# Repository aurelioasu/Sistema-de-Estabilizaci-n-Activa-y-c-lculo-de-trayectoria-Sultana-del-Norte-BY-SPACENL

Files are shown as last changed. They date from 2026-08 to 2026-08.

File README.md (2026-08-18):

<p align="center">
  Sultana del Norte — sistema de estabilización y corrección activa de vuelo
</p>

<p align="center">
  
  
  
  
  
  
</p>

<p align="center">
  <strong>Aviónica · control PID · cuatro superficies activas · telemetría · simulación 6-DoF · CFD</strong>
</p>

<p align="center">
  <a href="#descargar-la-aplicación">Descargar app</a> ·
  <a href="#explorar-el-proyecto">Explorar el proyecto</a> ·
  <a href="#arquitectura">Arquitectura</a> ·
  <a href="#galería">Galería</a> ·
  <a href="05-documentacion/informe-tecnico/Reporte-tecnico-Sultana-del-Norte-2026.pdf">Reporte técnico</a>
</p>

# Sultana del Norte

**Sultana del Norte** es un sistema integral de estabilización y corrección activa para un vehículo experimental de pequeño calibre, desarrollado por **Space NL** para ExpoCiencias Nuevo León 2026. El proyecto estudia cómo mitigar la desviación provocada por viento cruzado mediante estimación de actitud, control PID y cuatro canards accionados independientemente.

Este repositorio reúne el proyecto completo: diseño mecánico, evidencia CFD, esquemáticos y PCB, tres programas para ESP32-S3, código fuente de la aplicación Windows, simulación, telemetría, documentación técnica y descargas listas para usar.

> [!IMPORTANT]
> El firmware público calcula y registra las órdenes de control, pero mantiene la actuación física **bloqueada por defecto**. El sistema debe validarse en banco —cableado, sentidos, mezcla y límites— antes de habilitar cualquier movimiento.

## Explorar el proyecto

| Área | Qué contiene | Entrada principal |
|---|---|---|
| 🛰️ **Diseño CAD y aerodinámica** | STL del vehículo, integración del módulo, 21 renders y 72 capturas CFD organizadas por condición y ángulo | [`01-diseno-cad/`](01-diseno-cad/) |
| ⚡ **Electrónica y aviónica** | Esquemático, PCB, BOM interactiva y modelos STEP/OBJ/MTL | [`02-electronica/`](02-electronica/) |
| 🎛️ **Firmware ESP32-S3** | Diagnóstico, control de vuelo y estación terrestre, compilables con Arduino | [`03-firmware-esp32/`](03-firmware-esp32/) |
| 🖥️ **Aplicación Sultana** | Python/PySide6, núcleo C++, módulo Go, configuraciones, modelos, pruebas y compilador Windows | [`04-app-sultana/`](04-app-sultana/) |
| 📚 **Documentación** | Reporte final de 84 páginas, arquitectura, informe CAD y protocolo histórico claramente identificado | [`05-documentacion/`](05-documentacion/) |

## Qué hace el sistema

- Adquiere actitud, aceleración, presión barométrica y posición con BNO085, BMP390 y GPS.
- Ejecuta estimación de actitud y control a **200 Hz** en el ESP32-S3.
- Calcula órdenes limitadas para cuatro superficies activas en configuración cruciforme.
- Registra datos en microSD y transmite telemetría por nRF24L01.
- Recibe y rotula telemetría mediante una estación terrestre ESP32-S3.
- Simula trayectoria y dinámica de seis grados de libertad en la aplicación de escritorio.
- Visualiza mapas, telemetría, canards, fuerzas, Monte Carlo y dispersión de aterrizaje.
- Prepara casos CFD externos con OpenFOAM y ofrece un túnel de viento 2D cualitativo.
- Exporta resultados en CSV/Parquet y conserva escenarios configurables.

## Arquitectura

```mermaid
flowchart LR
    Sensors["BNO085 · BMP390 · GPS"] --> Flight["ESP32-S3<br/>estimación + PID a 200 Hz"]
    Flight --> Safety["interbloqueos<br/>límites ±12°"]
    Safety --> Actuators["4 canards"]
    Flight --> Storage["microSD"]
    Flight <--> AirRadio["nRF24L01<br/>telemetría v2"]
    AirRadio <--> Ground["estación terrestre<br/>ESP32-S3"]
    Ground --> App["app Sultana del Norte"]
    App --> Analysis["telemetría y análisis"]
    App --> SixDoF["simulación 6-DoF<br/>trayectoria"]
    App --> Aero["CFD / túnel 2D"]
```

La descripción de contratos, responsabilidades y límites entre componentes está en [arquitectura-del-sistema.md](05-documentacion/arquitectura/arquitectura-del-sistema.md).

## Descargar la aplicación

La Release [`v1.0.0`](https://github.com/aurelioasu/Sistema-de-Estabilizaci-n-Activa-y-c-lculo-de-trayectoria-Sultana-del-Norte-BY-SPACENL/releases/tag/v1.0.0) contiene dos opciones para Windows 10/11 x64:

| Descarga | Recomendación | Enlace |
|---|---|---|
| Paquete portable ZIP | **Recomendado.** Extrae la carpeta y ejecuta la aplicación; suele iniciar más rápido | [`Sultana-del-Norte-v1.0.0-Windows-x64-portable.zip`](https://github.com/aurelioasu/Sistema-de-Estabilizaci-n-Activa-y-c-lculo-de-trayectoria-Sultana-del-Norte-BY-SPACENL/releases/download/v1.0.0/Sultana-del-Norte-v1.0.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) |
| Ejecutable único | Un solo archivo; el primer inicio puede tardar más mientras prepara sus recursos | [`Sultana-del-Norte-v1.0.0-Windows-x64.exe`](https://github.com/aurelioasu/Sistema-de-Estabilizaci-n-Activa-y-c-lculo-de-trayectoria-Sultana-del-Norte-BY-SPACENL/releases/download/v1.0.0/Sultana-del-Norte-v1.0.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) |

El programa puede abrir y usar simulación, mapas, telemetría y vistas previas sin Docker. **Docker Desktop solo es necesario para ejecutar casos externos de OpenFOAM.**

> [!NOTE]
> Los binarios no tienen firma digital comercial. Windows SmartScreen puede mostrar una advertencia por editor desconocido. Compara el SHA-256 con `SHA256SUMS.txt` de la Release antes de ejecutar:
>
> ```powershell
> Get-FileHash .\Sultana-del-Norte-v1.0.0-Windows-x64.exe -Algorithm SHA256
> ```

## Galería

<table>
  <tr>
    <td width="50%" align="center">
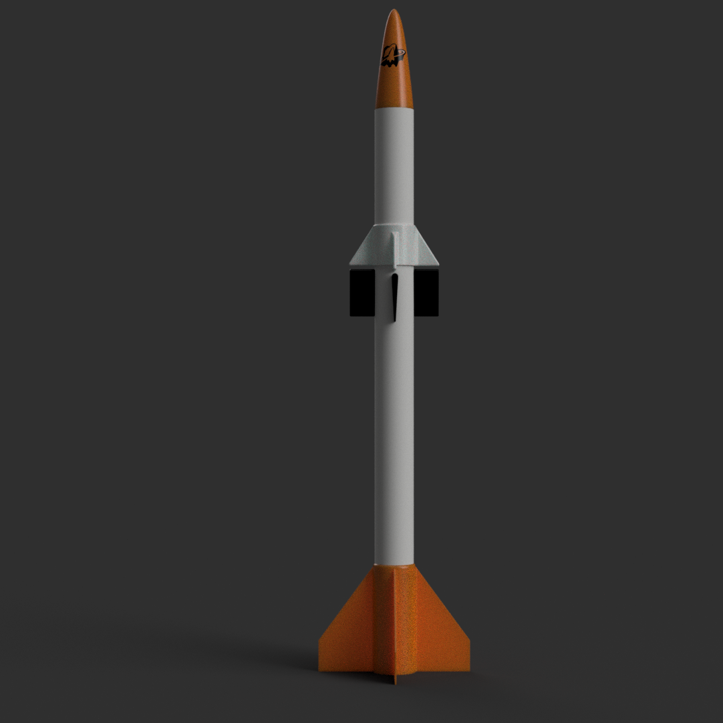
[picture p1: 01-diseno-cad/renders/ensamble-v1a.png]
Ensamble CAD de Sultana del Norte
      <br>
      <strong>Integración mecánica</strong><br>
      Vehículo y módulo de cuatro superficies activas.
    </td>
    <td width="50%" align="center">
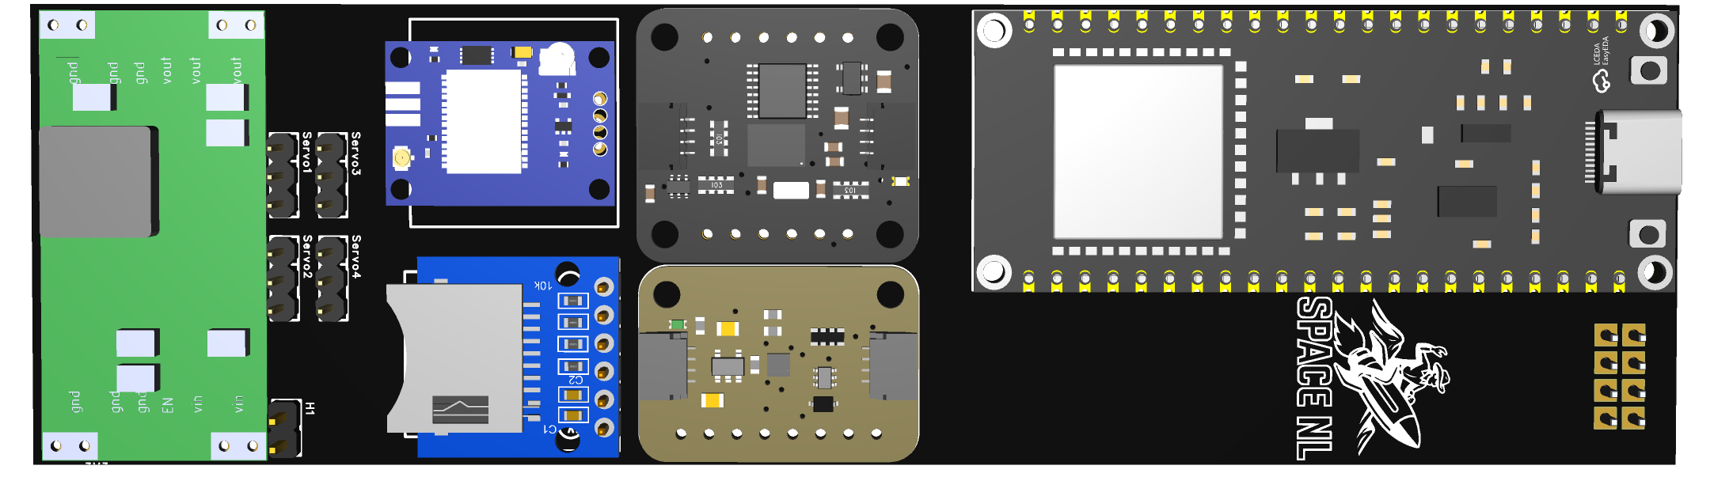
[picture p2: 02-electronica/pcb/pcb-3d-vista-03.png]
PCB y módulos de aviónica
      <br>
      <strong>Aviónica integrada</strong><br>
      ESP32-S3, sensores, radio, almacenamiento y salidas.
    </td>
  </tr>
  <tr>
    <td width="50%" align="center">
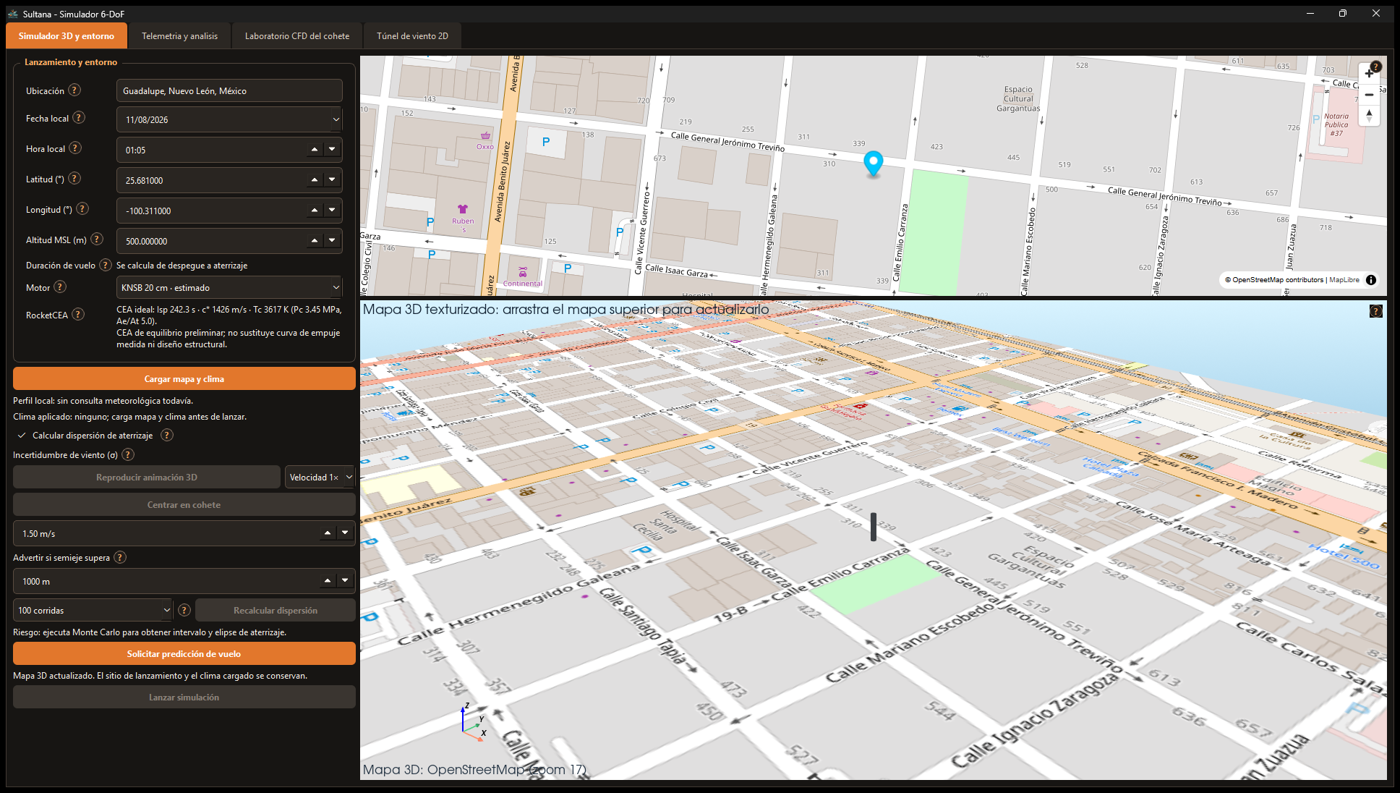
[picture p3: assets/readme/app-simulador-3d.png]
Simulador 3D y mapa de trayectoria
      <br>
      <strong>Simulación y trayectoria</strong><br>
      Escenario, entorno, mapa y reproducción tridimensional.
    </td>
    <td width="50%" align="center">
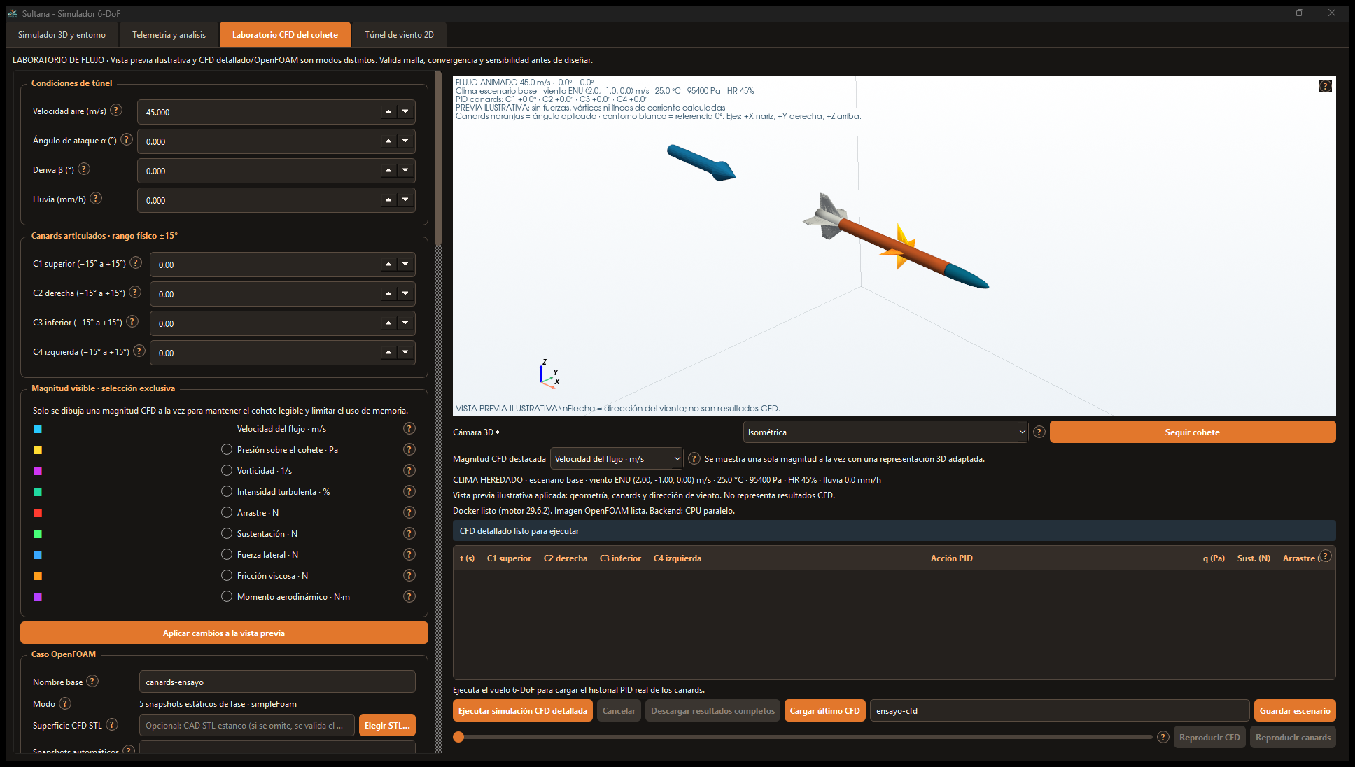
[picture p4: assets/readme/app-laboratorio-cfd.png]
Laboratorio CFD de la aplicación
      <br>
      <strong>Laboratorio aerodinámico</strong><br>
      Vista previa, canards, magnitudes y casos OpenFOAM.
    </td>
  </tr>
</table>

<details>
<summary><strong>Ver telemetría y evidencia de diseño adicionales</strong></summary>

<br>

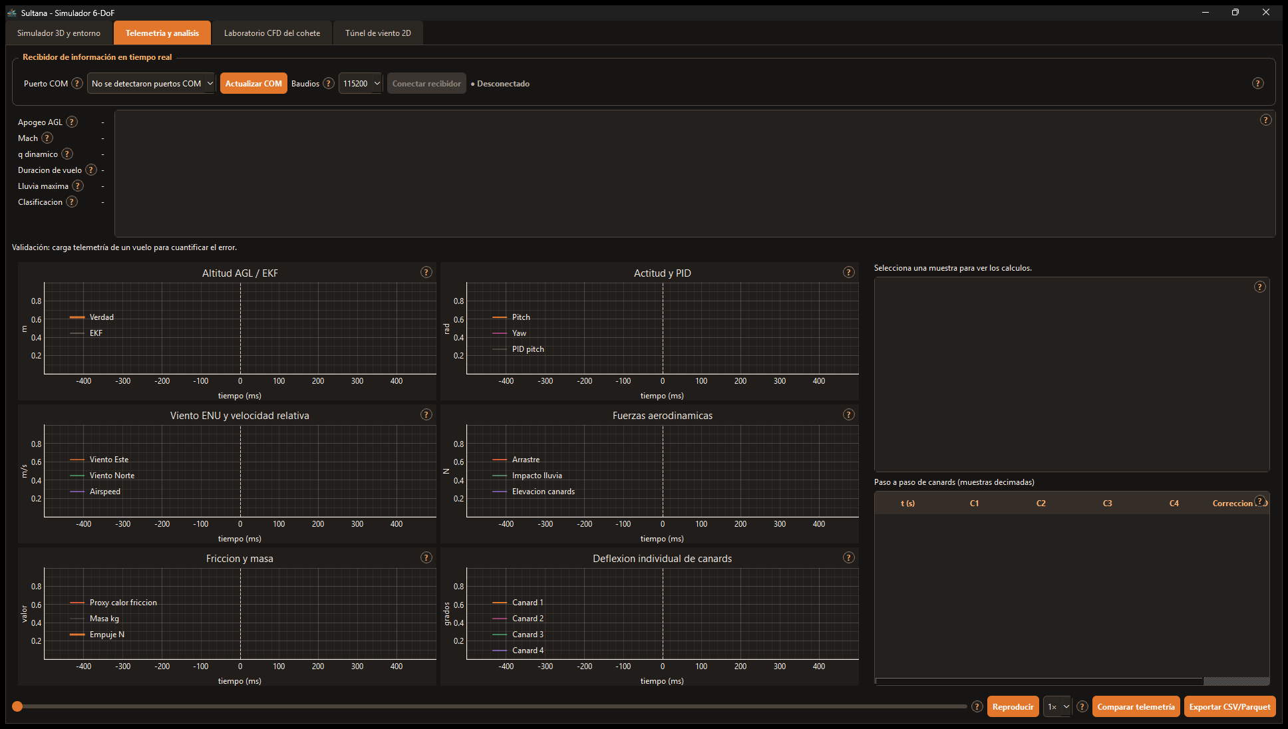
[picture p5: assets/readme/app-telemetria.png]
Panel de telemetría y análisis


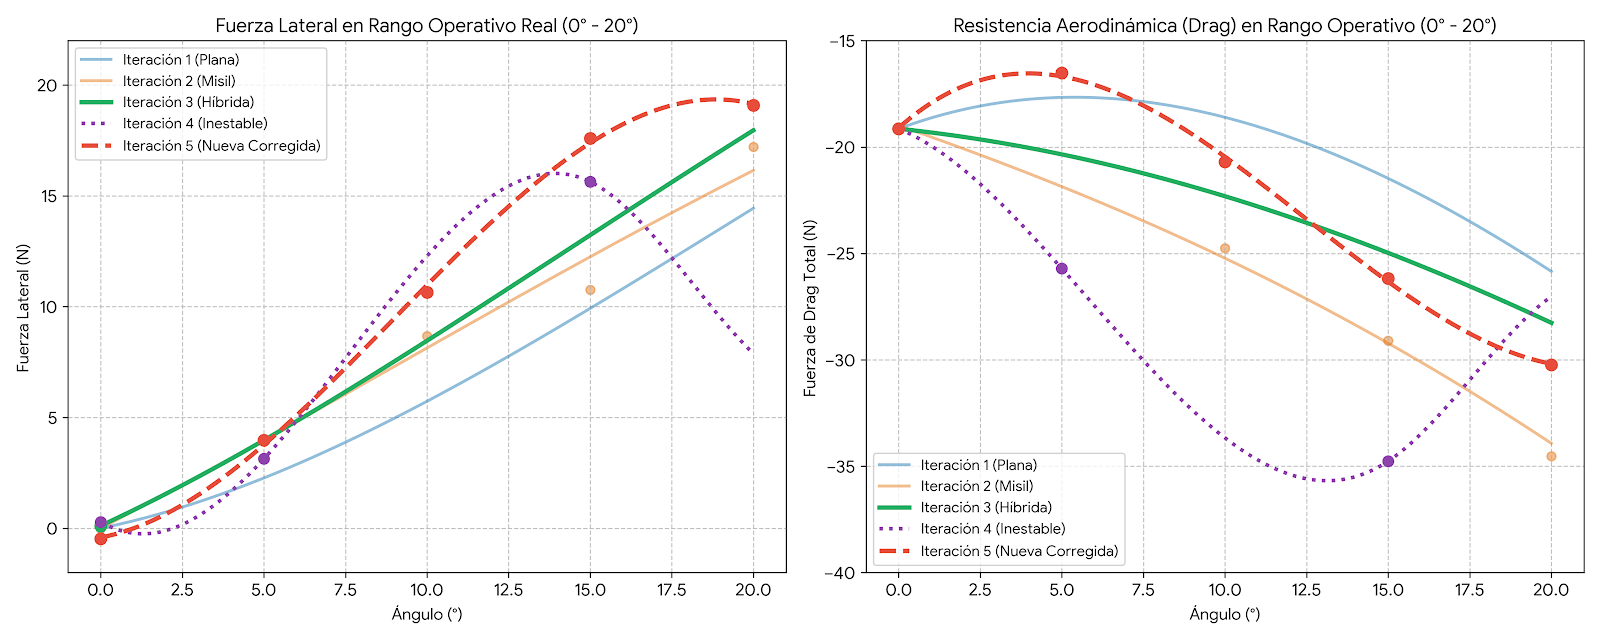
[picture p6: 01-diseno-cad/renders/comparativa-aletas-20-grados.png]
Comparativa aerodinámica de cinco iteraciones


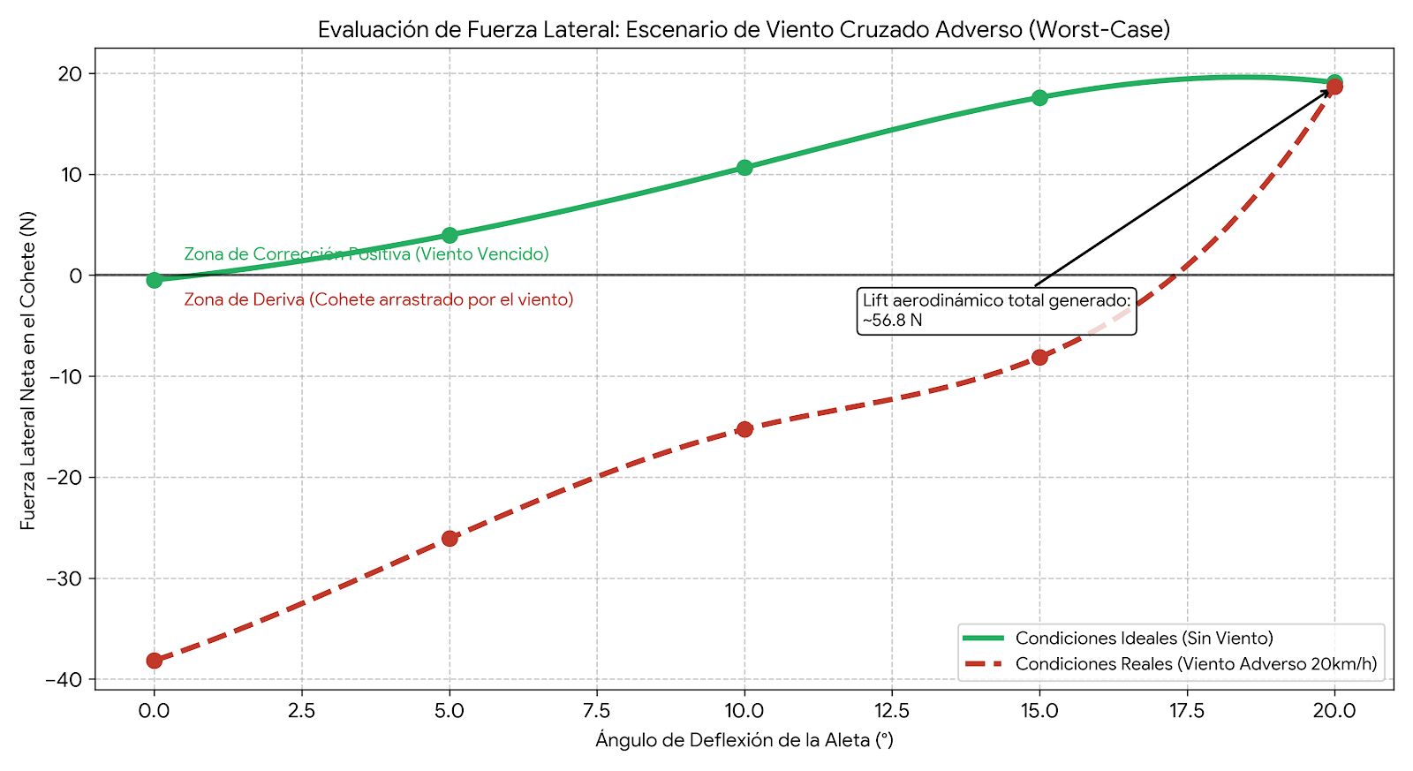
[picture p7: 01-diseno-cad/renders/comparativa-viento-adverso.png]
Evidencia CFD con viento adverso


</details>

## Estado técnico de `v1.0.0`

| Componente | Verificación de referencia |
|---|---|
| Diagnóstico ESP32-S3 | Compila con ESP32 core 3.3.2; 455 483 bytes de flash |
| Control de vuelo ESP32-S3 | Compila con ESP32 core 3.3.2; 429 243 bytes de flash |
| Estación terrestre ESP32-S3 | Compila con ESP32 core 3.3.2; 321 739 bytes de flash |
| Aplicación Python | 112 pruebas superadas |
| Núcleo físico C++ | Compilación Release y 1/1 prueba CTest superada |
| Módulo Kutta/Go | Pruebas superadas en sus paquetes |
| Higiene del repositorio | 16 pruebas de estructura, identidad, secretos y contratos |

Los comandos exactos y las dependencias verificadas están en los README de [firmware](03-firmware-esp32/README.md) y [aplicación](04-app-sultana/README.md).

## Compilar desde el código

### Firmware

Con Arduino CLI, el núcleo ESP32 3.3.2 y las bibliotecas indicadas en [`03-firmware-esp32/README.md`](03-firmware-esp32/README.md):

```powershell
arduino-cli compile --fqbn esp32:esp32:esp32s3 03-firmware-esp32/diagnostico/Diagnostico_Sultana
arduino-cli compile --fqbn esp32:esp32:esp32s3 03-firmware-esp32/control-de-vuelo/Control_Vuelo_Sultana
arduino-cli compile --fqbn esp32:esp32:esp32s3 03-firmware-esp32/estacion-terrena/Estacion_Terrena_Sultana
```

### Aplicación

La aplicación requiere Python 3.11+, Visual Studio Build Tools con C++, CMake y las dependencias declaradas:

```powershell
cd 04-app-sultana
python -m venv .venv
.\.venv\Scripts\python.exe -m pip install -e ".[3d,export,dev]"
.\.venv\Scripts\python.exe run_all.py --no-install
.\.venv\Scripts\python.exe -m app.bootstrap
```

Consulta la [guía completa de la aplicación](04-app-sultana/README.md) para compilar el núcleo, Kutta y el ejecutable Windows.

## Estructura

```text
.
├── 01-diseno-cad/          # STL, renders y evidencia CFD
├── 02-electronica/         # esquemáticos, PCB, BOM y modelos 3D
├── 03-firmware-esp32/      # diagnóstico, vuelo y estación terrestre
├── 04-app-sultana/         # Python, C++, Go, datos y pruebas
├── 05-documentacion/       # informe final, arquitectura y material curado
├── assets/readme/          # portada y capturas optimizadas para GitHub
├── LICENSES/               # licencias de terceros
├── MANIFESTO_DE_CONTENIDO.md
└── THIRD_PARTY_NOTICES.md
```

Los inventarios CSV de CAD, electrónica y documentación registran origen, tamaño y SHA-256. El [manifiesto](MANIFESTO_DE_CONTENIDO.md) explica duplicados, exclusiones y material reservado para Releases.

## Validación, límites y seguridad

> [!CAUTION]
> Este repositorio documenta un sistema experimental. No constituye certificación de aeronavegabilidad ni autorización de lanzamiento.

- La reducción de desviación indicada en el informe corresponde al criterio declarado en escenarios HIL/modelados de hasta 25 km/h; el paquete no contiene series crudas activo/pasivo para reproducir esa cifra.
- Las 72 capturas CFD son evidencia visual de iteración. No sustituyen malla, caso de solver, convergencia ni ensayo físico.
- Al cierre documental del 17 de agosto de 2026, la campaña de vuelo final seguía pendiente.
- El esquema electrónico V1.0 y el pinout vigente del firmware difieren en SDA y tres canales de servo. Revisa la [tabla de discrepancias](02-electronica/README.md#diferencias-pendientes-frente-al-firmware) y confirma continuidad sobre el hardware real.
- Los seguros `PERMITIR_MOVIMIENTO_CANARDS`, `MEZCLA_Y_SENTIDOS_VALIDADOS` y `HABILITAR_SALIDA_PARACAIDAS` se distribuyen en `false`.
- Nunca conectes una carga de despliegue directamente a un GPIO. Inmoviliza el vehículo y trabaja sin propulsión durante pruebas de banco.

## Documentación y material pesado

- [Reporte técnico final — PDF](05-documentacion/informe-tecnico/Reporte-tecnico-Sultana-del-Norte-2026.pdf)
- [Reporte técnico final — DOCX editable](05-documentacion/informe-tecnico/Reporte-tecnico-Sultana-del-Norte-2026.docx)
- [Documentación curada y estados de revisión](05-documentacion/README.md)
- [Notas de la versión v1.0.0](docs/releases/v1.0.0.md)
- [Video principal del proyecto](https://github.com/aurelioasu/Sistema-de-Estabilizaci-n-Activa-y-c-lculo-de-trayectoria-Sultana-del-Norte-BY-SPACENL/releases/download/v1.0.0/Sultana-del-Norte-ExpoC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)
- [Material técnico y multimedia](https://github.com/aurelioasu/Sistema-de-Estabilizaci-n-Activa-y-c-lculo-de-trayectoria-Sultana-del-Norte-BY-SPACENL/releases/download/v1.0.0/Sultana-del-Norte-v1.0.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)
- [Sumas SHA-256](https://github.com/aurelioasu/Sistema-de-Estabilizaci-n-Activa-y-c-lculo-de-trayectoria-Sultana-del-Norte-BY-SPACENL/releases/download/v1.0.0/SHA256SUMS.txt)

Los videos, fotografías completas, visualizadores interactivos y paquetes pesados viven en GitHub Releases para mantener el historial Git ligero.

## Equipo

Proyecto desarrollado por la comunidad **Space NL**:

- Aurelio Salas González
- Gael Sebastián García Azpeytia
- [Sergio Axell Flores Obando](https://github.com/Hir0qwq) · coautor y colaborador
- Asesor: Fernando Alonso Villalobos

<p align="center">
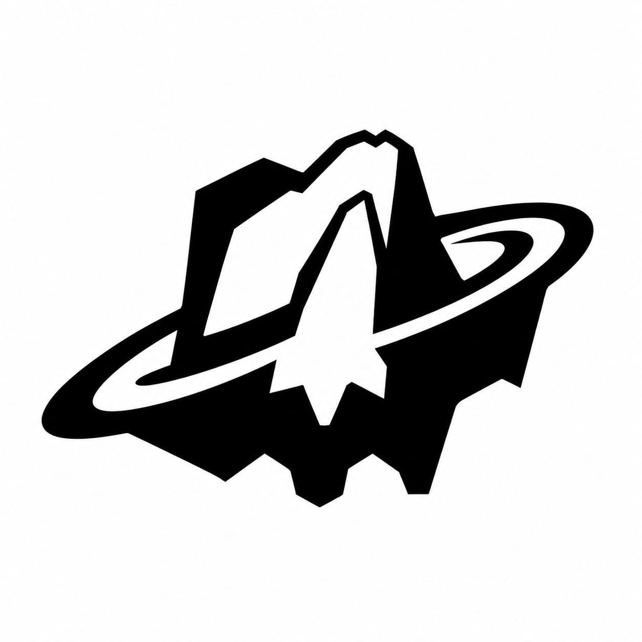
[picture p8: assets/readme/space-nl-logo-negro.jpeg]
Space NL
  <br>
  <sub>Monterrey, Nuevo León · 2026</sub>
</p>

## Licencias y atribuciones

El componente [Kutta](04-app-sultana/kutta/) fue desarrollado por Cesar Gimenes y se conserva bajo licencia MIT. Consulta [`LICENSES/Kutta-MIT.txt`](LICENSES/Kutta-MIT.txt) y [`THIRD_PARTY_NOTICES.md`](THIRD_PARTY_NOTICES.md).

El trabajo propio del repositorio no incluye por ahora una licencia abierta en la raíz; por ello no se concede automáticamente permiso para copiar, modificar o redistribuir ese contenido. Las licencias de terceros conservan todos sus efectos.

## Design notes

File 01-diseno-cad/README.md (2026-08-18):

# Diseño CAD y aerodinámica

Modelos mecánicos, renders y evidencias CFD del vehículo Sultana del Norte y su sistema de superficies de control.

Ensamble de Sultana del Norte

## Contenido

| Ruta | Descripción |
| --- | --- |
| [`modelos/`](modelos/) | Modelo STL listo para inspección o fabricación |
| [`renders/`](renders/) | Ensamble, canards, comparativas y resultados de diseño |
| [`simulacion-cfd/`](simulacion-cfd/) | Capturas organizadas por condición y ángulo |
| [`material-complementario/`](material-complementario/) | Plano de propulsión separado del sistema de control |
| [`INVENTARIO.csv`](INVENTARIO.csv) | Origen, destino, tamaño y SHA-256 de cada archivo |

## Modelo 3D

El archivo principal es [`sultana-del-norte-final-naca.stl`](modelos/sultana-del-norte-final-naca.stl). La entrega contenía un STL “final corregido” y otro de “validación”; ambos tienen exactamente el mismo SHA-256, por lo que se conserva una sola copia con un nombre inequívoco.

Los modelos usados internamente por la aplicación —OBJ, STL y VTP— se encuentran en [`04-app-sultana/data/models/`](../04-app-sultana/data/models/).

## Evidencia CFD

Las 72 capturas se normalizaron en dos familias a 171 m/s:

| Ángulo | Turbulencia | Condiciones reales |
| ---: | ---: | ---: |
| 0° | 7 | 5 |
| 5° | 8 | 6 |
| 10° | 5 | 7 |
| 15° | 9 | 7 |
| 20° | 11 | 7 |

Las imágenes permiten comparar campos y tendencias, pero no contienen por sí solas una malla, un caso de solver ni todos los parámetros necesarios para reproducir el cálculo. Por ello se presentan como evidencia visual de la iteración de diseño, no como validación aerodinámica definitiva.

Comparativa con viento adverso

## Material pesado

Los giros interactivos, MP4 y ZIP de visualización se incluirán en la Release `v1.0.0`. Se omitieron del historial normal las copias exactas que aparecían simultáneamente en las carpetas de documentación y renders.

## Material complementario de propulsión

[`plano-motor-knsb-snl-220-01.pdf`](material-complementario/plano-motor-knsb-snl-220-01.pdf) es un plano independiente del motor. Se conserva como referencia de propulsión y no debe interpretarse como plano del mecanismo de estabilización activa.

## Antes de fabricar

- Confirma unidades, escala y tolerancias en el programa CAD.
- Verifica holguras, ejes y límites mecánicos de los canards.
- Realiza pruebas de banco sin propulsión y con actuadores desenergizados al montar.
- No uses una captura CFD como sustituto de verificación estructural o aerodinámica.

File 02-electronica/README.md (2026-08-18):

# Electrónica

Esquemáticos, PCB, lista de materiales y modelos tridimensionales de la aviónica de Sultana del Norte.

PCB de Sultana del Norte

## Contenido

| Ruta | Descripción |
| --- | --- |
| [`esquematicos/`](esquematicos/) | Esquema completo en SVG y PNG |
| [`pcb/`](pcb/) | Layout, vistas 2D/3D y captura del editor |
| [`bom/interactive-bom.html`](bom/interactive-bom.html) | Lista de materiales interactiva |
| [`modelos-3d/`](modelos-3d/) | PCB en STEP, OBJ y MTL |
| [`recursos/`](recursos/) | Identidad visual usada en el diseño |
| [`INVENTARIO.csv`](INVENTARIO.csv) | Origen, destino, tamaño y SHA-256 |

## Revisión disponible

El esquemático se identifica como `Schematic1`, versión V1.0, actualizado el 10 de agosto de 2026. Incluye ESP32-S3, BNO085, BMP390, GPS MAX10S, microSD, nRF24L01, cuatro conectores de servo y regulación de alimentación.

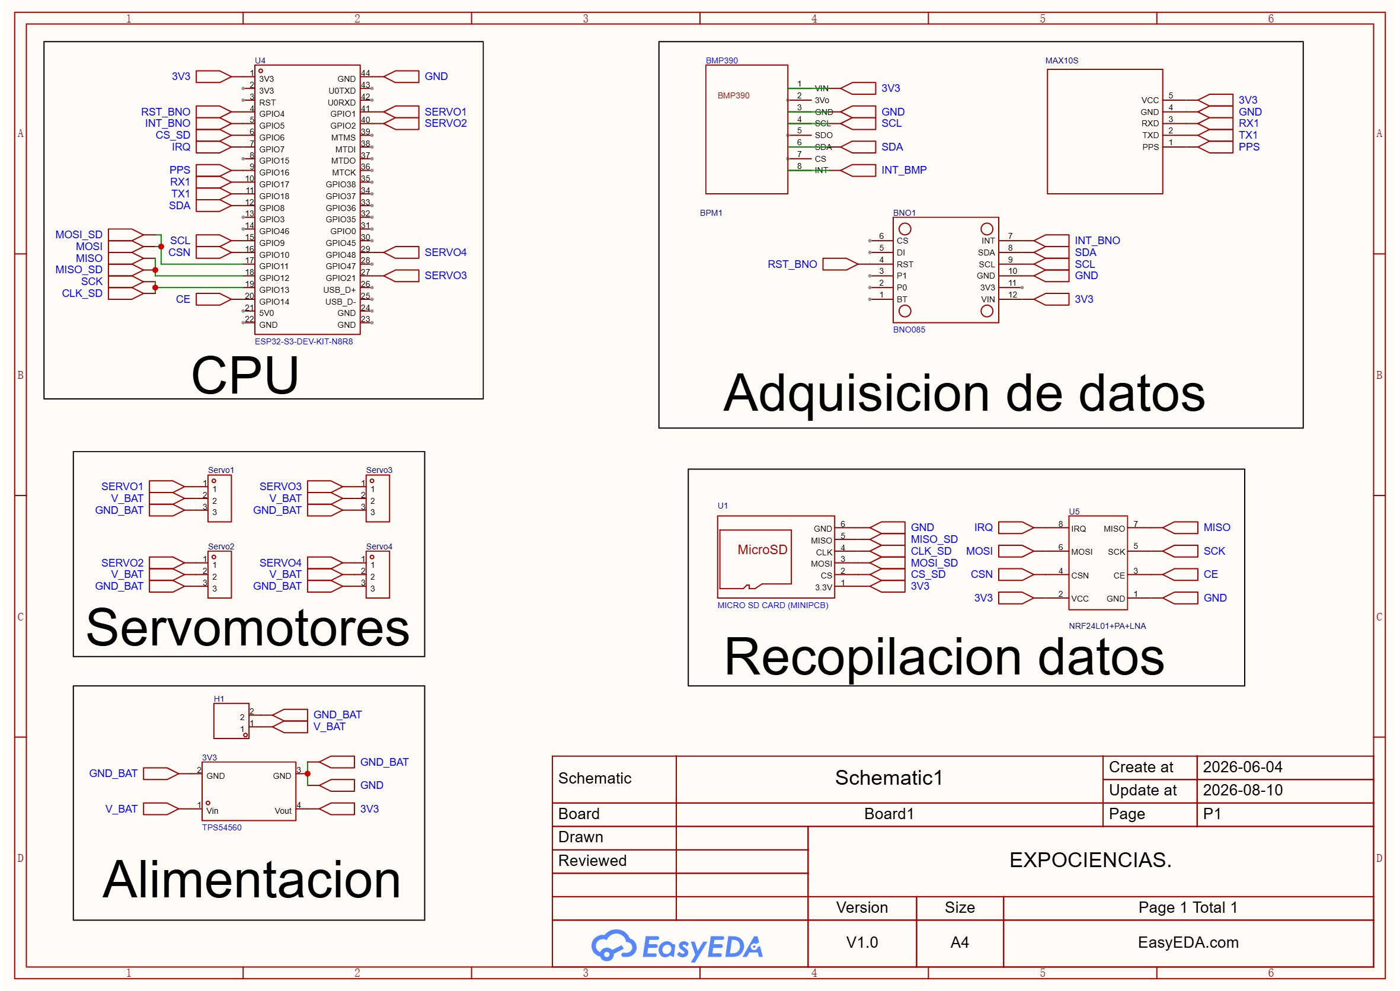
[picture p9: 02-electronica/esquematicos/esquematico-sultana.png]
Esquemático de la aviónica


## Diferencias pendientes frente al firmware

La revisión visual del esquema y el mapa vigente del firmware no coinciden en estas señales:

| Señal | Esquemático V1.0 | Firmware `v1.0.0` |
| --- | ---: | ---: |
| I²C SDA | GPIO 8 | GPIO 18 |
| Servo 1 | GPIO 1 | GPIO 41 |
| Servo 2 | GPIO 2 | GPIO 2 |
| Servo 3 | GPIO 47 | GPIO 21 |
| Servo 4 | GPIO 48 | GPIO 47 |

> [!CAUTION]
> Esta tabla documenta una discrepancia; no decide cuál revisión corresponde a la PCB fabricada. Comprueba continuidad y arnés físico antes de alimentar el sistema. Los bloqueos de movimiento del firmware deben permanecer en `false` hasta completar esa validación.

## Archivos para fabricación e inspección

- [`pcb-sultana.step`](modelos-3d/pcb-sultana.step): modelo mecánico de intercambio.
- [`pcb-sultana.obj`](modelos-3d/pcb-sultana.obj) y [`pcb-sultana.mtl`](modelos-3d/pcb-sultana.mtl): visualización de malla y materiales.
- [`interactive-bom.html`](bom/interactive-bom.html): localización y revisión de componentes.
- [`esquematico-sultana.svg`](esquematicos/esquematico-sultana.svg): versión vectorial del diagrama.

## Seguridad eléctrica

- No alimentes servos desde el regulador lógico de 3.3 V.
- Verifica tierra común, polaridad y corriente disponible antes de conectar cargas.
- No conectes directamente una carga de despliegue al GPIO de alerta.
- Valida la PCB y el firmware como una pareja de revisiones antes de cualquier ensayo dinámico.

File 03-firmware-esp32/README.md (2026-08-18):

# Firmware ESP32-S3

Esta sección contiene los tres programas de aviónica de Sultana del Norte. Los sketches se mantienen separados para que cada función pueda probarse y cargarse desde Arduino IDE sin depender de la aplicación de escritorio.

## Programas

| Programa | Función | Ruta |
| --- | --- | --- |
| Diagnóstico | Pruebas de sensores, almacenamiento, GPS, radio y servos en banco | [`diagnostico/Diagnostico_Sultana/`](diagnostico/Diagnostico_Sultana/) |
| Control de vuelo | Estimación de actitud, control PID, telemetría y máquina de estados | [`control-de-vuelo/Control_Vuelo_Sultana/`](control-de-vuelo/Control_Vuelo_Sultana/) |
| Estación terrena | Recepción nRF24 y salida de telemetría por puerto serie | [`estacion-terrena/Estacion_Terrena_Sultana/`](estacion-terrena/Estacion_Terrena_Sultana/) |

## Plataforma verificada

- Tarjeta: ESP32-S3 Dev Module
- FQBN: `esp32:esp32:esp32s3`
- Núcleo ESP32: 3.3.2
- Monitor serie: 115200 baud
- Radio: nRF24L01, canal 76, 250 kbps, CRC de 16 bits
- Dirección del proyecto: `SNL01`
- Protocolo de telemetría: versión 2, paquetes de 32 bytes

Bibliotecas verificadas:

- Adafruit BNO08x 1.2.5
- Adafruit BMP3XX 2.1.6
- Adafruit BusIO
- Adafruit Unified Sensor
- ESP32Servo 3.1.3
- RF24 1.5.0
- TinyGPSPlus

## Mapa de pines vigente en el firmware

| Señal | GPIO |
| --- | ---: |
| BNO085 reset | 4 |
| BNO085 interrupción | 5 |
| microSD CS | 6 |
| nRF24 IRQ | 7 |
| I²C SCL | 9 |
| nRF24 CSN | 10 |
| SPI MOSI | 11 |
| SPI MISO | 12 |
| SPI SCK | 13 |
| nRF24 CE | 14 |
| GPS PPS | 15 |
| GPS RX | 16 |
| GPS TX | 17 |
| I²C SDA | 18 |
| Servos 1–4 | 41, 2, 21, 47 |
| Alerta de paracaídas | 40 |

> [!CAUTION]
> Algunos archivos visuales de electrónica corresponden a una revisión distinta del cableado. Antes de energizar actuadores, valida este mapa contra la PCB fabricada y el arnés físico.

## Bloqueos de seguridad

El control de vuelo se distribuye con estas salidas deshabilitadas:

```cpp
const bool PERMITIR_MOVIMIENTO_CANARDS = false;
const bool MEZCLA_Y_SENTIDOS_VALIDADOS = false;
const bool HABILITAR_SALIDA_PARACAIDAS = false;
```

No cambies estos valores hasta terminar la calibración mecánica, confirmar los sentidos de cada servo y validar la matriz de mezcla. La salida de alerta nunca debe conectarse directamente a una carga de despliegue.

## Compilación

Desde la raíz del repositorio, con Arduino CLI y el núcleo ESP32 instalados:

```powershell
arduino-cli compile --fqbn esp32:esp32:esp32s3 03-firmware-esp32/diagnostico/Diagnostico_Sultana
arduino-cli compile --fqbn esp32:esp32:esp32s3 03-firmware-esp32/control-de-vuelo/Control_Vuelo_Sultana
arduino-cli compile --fqbn esp32:esp32:esp32s3 03-firmware-esp32/estacion-terrena/Estacion_Terrena_Sultana
```

## Comandos de banco

El sketch de diagnóstico exige la frase `ARMAR SERVOS X08` antes de generar PWM. El control de vuelo acepta `ARMAR SULTANA`, `DESARMAR` y `ESTADO`; aun así, los canards siguen bloqueados mientras los dos seguros de movimiento permanezcan en `false`.

## Resultado de compilación de referencia

| Programa | Flash | RAM global |
| --- | ---: | ---: |
| Diagnóstico | 455 483 bytes | 27 320 bytes |
| Control de vuelo | 429 243 bytes | 27 808 bytes |
| Estación terrena | 321 739 bytes | 20 800 bytes |

Resultados obtenidos el 17 de agosto de 2026 con ESP32 core 3.3.2. El tamaño puede variar ligeramente entre versiones del compilador.

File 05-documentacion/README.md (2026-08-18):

# Documentación de Sultana del Norte

Esta sección reúne la documentación técnica curada del **sistema de estabilización y corrección activa de vuelo Sultana del Norte**. Los archivos se separan por vigencia para evitar que un documento anterior se interprete como la definición actual del hardware o del software.

## Documento vigente

| Documento | Estado | Formatos |
|---|---|---|
| Reporte técnico Sultana del Norte 2026 | **Referencia integral vigente** | [PDF](informe-tecnico/Reporte-tecnico-Sultana-del-Norte-2026.pdf) · [DOCX editable](informe-tecnico/Reporte-tecnico-Sultana-del-Norte-2026.docx) |

El reporte técnico de 84 páginas integra planteamiento, arquitectura, electrónica, modelo físico, control, firmware, CAD, CFD, aplicación, validación declarada, limitaciones y anexos. Cuando exista una discrepancia con un documento de mayo de 2026, prevalecen el código versionado, los README de cada área y este reporte final.

## Material complementario

| Documento | Estado | Uso recomendado | Formatos |
|---|---|---|---|
| Informe de diseño CAD | Complementario | Geometría, integración mecánica, configuración de cuatro superficies y CFD preliminar | [PDF](material-complementario/Informe-diseno-CAD-Sultana-del-Norte.pdf) · [DOCX](material-complementario/Informe-diseno-CAD-Sultana-del-Norte.docx) |
| Protocolo ExpoCiencias NL, mayo de 2026 | **Histórico** | Trazabilidad del desarrollo y de la propuesta inicial | [PDF](material-complementario/Protocolo-ExpoCiencias-NL-mayo-2026.pdf) · [DOCX](material-complementario/Protocolo-ExpoCiencias-NL-mayo-2026.docx) |

> [!CAUTION]
> El protocolo de mayo describe una etapa anterior —incluidos BNO055, dos canards y frecuencias preliminares—. No debe usarse como mapa de conexiones, lista de componentes ni especificación de firmware vigente.

## Manuales operativos vigentes

- [Aplicación Sultana del Norte](../04-app-sultana/README.md): instalación, ejecución, telemetría, simulación, CFD y compilación.
- [Firmware ESP32-S3](../03-firmware-esp32/README.md): sketches, bibliotecas, compilación, pines y bloqueos de seguridad.
- [Electrónica y aviónica](../02-electronica/README.md): esquemáticos, PCB, BOM y discrepancias que requieren validación física.
- [Diseño CAD y CFD](../01-diseno-cad/README.md): modelo 3D, renders, condiciones simuladas e inventario.

## Arquitectura

La vista compacta de componentes y flujo de datos está en [arquitectura-del-sistema.md](arquitectura/arquitectura-del-sistema.md).

## Curaduría

Los manuales antiguos que todavía presentaban el proyecto bajo una identidad ajena no se publicaron: su contenido útil se consolidó en los README vigentes. Los documentos incluidos fueron revisados tanto en texto como visualmente; los PDF son exportaciones verificadas de sus fuentes DOCX. Los tamaños y hashes de estos archivos están en [INVENTARIO.csv](INVENTARIO.csv).

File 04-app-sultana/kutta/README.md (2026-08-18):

# kutta - 2D wind tunnel

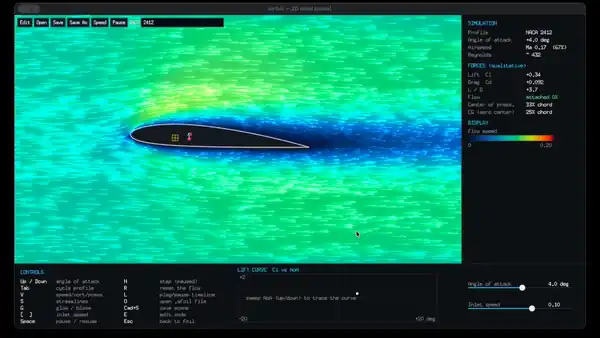
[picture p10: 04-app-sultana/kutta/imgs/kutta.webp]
kutta


A 2D wind tunnel for aeromodelers and anyone who likes watching air misbehave.
It streams a flow past an airfoil and draws the speed field, the vorticity, smoke
streaklines and the lift/drag vectors while you turn the angle of attack. You can
also draw your own shape, cut a wing into wing + flap, animate the control
surfaces, and watch the wake fall apart when you push the angle too far.

It is **qualitative, not validated CFD**. Lattice units stand in for physical
ones, so it gets the *shape* of the flow right (stagnation point, wake, suction
over the top, separation as the angle grows) and the actual numbers wrong. Use it
for intuition and for a demo that looks good on a projector, not for sizing a real
wing.

Written in Go with [Ebitengine](https://ebitengine.org). One executable, nothing
to install alongside it.

## Try it in your browser

**[Open the wind tunnel →](https://crgimenes.github.io/kutta/)**

The whole simulator runs as WebAssembly, with nothing to install. A browser tab
cannot reach your files, so opening and saving `.afoil` scenes, importing SVG and
the native menu are desktop only.

## Download (no Go required)

Grab a prebuilt binary from the
[latest release](https://github.com/crgimenes/kutta/releases/latest). You do
**not** need Go or any developer tools.

| System | File to download |
| --- | --- |
| macOS (Intel or Apple Silicon) | `kutta-darwin-universal.zip` |
| Windows (64-bit, most common) | `kutta-windows-amd64.exe` |
| Windows (ARM) | `kutta-windows-arm64.exe` |
| Linux (Intel/AMD 64-bit) | `kutta-linux-amd64.gz` |
| Linux (ARM 64-bit) | `kutta-linux-arm64.gz` |

### macOS

With [Homebrew](https://brew.sh), one command:

```bash
brew install --cask crgimenes/tap/kutta
```

Or by hand:

1. Download `kutta-darwin-universal.zip` and double-click it to unzip. You get
   `kutta.app`.
2. Move `kutta.app` to your **Applications** folder.
3. Double-click it to run.

The app is signed and notarized by Apple, so it opens normally. The single
universal build runs on both Intel and Apple Silicon, so there is no architecture
to choose.

If macOS says **"kutta.app is damaged and can't be opened"** or complains about
an unidentified developer:

- Make sure the download finished, and unzip before opening (do not run the app
  from inside the `.zip`). Re-download if in doubt.
- Right-click `kutta.app`, choose **Open**, then confirm with **Open** in the
  dialog.
- If it still refuses, open **Terminal** and run (adjust the path if you did not
  move it to Applications):

  ```bash
  xattr -dr com.apple.quarantine /Applications/kutta.app
  ```

### Windows

Download the `.exe` for your machine and double-click it. Windows SmartScreen may
warn you because the app is not from the Microsoft Store: click
**More info → Run anyway**.

### Linux

Download the matching `.gz`, then decompress and run:

```bash
gunzip kutta-linux-amd64.gz
chmod +x kutta-linux-amd64
./kutta-linux-amd64
```

## Run from source

With Go installed:

```bash
go run .
```

On macOS and Windows there is nothing else to install. On **Linux**, Ebitengine
needs Cgo and the system development libraries, so build with `CGO_ENABLED=1`
after installing the packages from the
[Ebitengine install guide](https://ebitengine.org/en/documents/install.html) (on
Debian/Ubuntu: `libgl1-mesa-dev`, `libasound2-dev`, `libxcursor-dev`, `libxi-dev`,
`libxinerama-dev`, `libxrandr-dev`, `libxxf86vm-dev`, `pkg-config`).

## Command-line flags

| Flag | Effect |
| --- | --- |
| `-scene path.afoil` | load a scene at startup instead of the interactive foil |
| `-fullscreen` | start in full screen |
| `-hidecontrols` | hide every panel and control, showing only the flow image |

The flags combine into a kiosk. `kutta -scene wing.afoil -fullscreen -hidecontrols`
boots straight into a scene, full screen, with nothing on screen but the flow.
The keys still work, so a controller wired to the keyboard (or a person) can drive
angle of attack and speed with no visible UI. A bad `-scene` path logs a warning
and falls back to the normal foil rather than failing to start.

## Controls

| Key | Action |
| --- | --- |
| ↑ / ↓ | angle of attack |
| Tab | cycle NACA profile |
| V | speed / vorticity / pressure field |
| S | streamlines |
| G | glow / bloom |
| `[` `]` | inlet speed |
| Space | pause / resume |
| N | single step (while paused) |
| R | reset the flow |
| E | open the editor |
| O | open an `.afoil` scene |
| Cmd+O | open (native file dialog) |
| Cmd+S | save |
| Cmd+Shift+S | save as |
| L | play / pause the animation |
| Esc | back to the foil |

Type a code in the field at the top (`2412`, `0012`, `23012`, ...) to pick any
NACA 4- or 5-digit foil, not just the ones on Tab. And if you type `neko` in that
field, you get a cat. It has terrible aerodynamics. That is the point.

## The editor

Press **E**. Draw a shape with the pen, drag its vertices, and curve an edge by
pulling out a Bézier handle. Cut a closed outline at a vertex and rejoin two loose
ends to split one airfoil into separate parts, which is how you turn a wing into
wing + flap that each follow the real profile.

**Tab** switches between geometry and animate. In animate you scrub a timeline and
drop a keyframe for each part's pose, so a flap can deploy and retract on a loop
while the flow keeps running. Scenes save as `.afoil`, a small
[Filo](https://github.com/crgimenes/filo) s-expression file; see `examples/` for a
few (`flap.afoil`, `neko.afoil`).

Geometry does not have to be drawn by hand or be an airfoil at all. **File →
Import SVG…** — or simply **dragging an `.svg` or `.afoil` file onto the
window** — loads a vector drawing as a scene: one object per subpath, with
curves flattened and the group scaled onto the grid. A car silhouette, a
building section or a bridge deck from Inkscape or Illustrator drops straight
into the tunnel. (On Windows and Linux the native file dialogs are not wired
up yet, so drag and drop is the way to open files there.) Scene files can
also reference drawings directly with
`(svg "path" chord leadX leadY [subpath])`, alongside the existing
`(naca "2412" ...)` and `(dat "file.dat" ...)` sources. Transforms are not
interpreted (flatten them before exporting) and holes become solid.

## How it works

- **Solver** (`lbm`): a 2D Lattice-Boltzmann method (D2Q9, BGK). An open channel
  with a free stream from the left; the body is a no-slip wall via half-way
  bounce-back. Forces come from a pressure integral over the body faces, so it
  captures form drag and lift. Skin friction is ignored, which means drag is
  understated. That is a known limit, not a bug to file.
- **Geometry** (`foil`): NACA 4- and 5-digit airfoils straight from their
  closed-form equations. A whole catalog with nothing stored on disk.
- **Scenes** (`scene`, `sceneio`): multi-object shapes with per-vertex Bézier
  handles, cuts, and keyframe animation, read and written as `.afoil`.
- **Visualization** (`viz`): color maps for the scalar fields and a smoke-tracer
  particle system pushed around by the velocity field.
- **App** (`main.go`, `game.go`, `editor.go`): the Ebitengine loop, the editor,
  and the native macOS/Windows menu (via [glaze](https://github.com/crgimenes/glaze)).

`lbm`, `foil`, `scene` and `viz` carry no rendering dependency and are unit tested
headlessly. `cmd/snapshot` renders the fields to PNG without a GPU, which is how
the physics gets sanity-checked: lift rising with angle of attack, the drag
bucket, the force signs coming out right.

## Gallery

Scenes built in the editor and run in the tunnel. Each one is an `.afoil` file
under [`examples/`](examples/), so you can open it yourself with
`kutta -scene examples/<name>.afoil`.

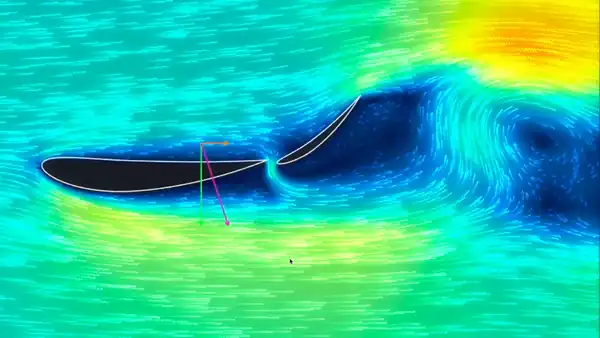
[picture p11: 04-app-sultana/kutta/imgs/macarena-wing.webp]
Ferrari's Macarena rear wing simulated in kutta


**Ferrari's "Macarena" rear wing.** The upper element rotates flat on the
straight and the wake behind it collapses, dropping downforce by more than half,
then swings back for the corner. Both profiles are inverted NACA sections, so
lift is negative: this wing pushes down.
Scene: [`examples/macarena.afoil`](examples/macarena.afoil).

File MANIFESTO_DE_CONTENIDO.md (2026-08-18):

# Manifiesto de contenido

Este documento registra cómo se transforma la entrega original en la publicación curada de Sultana del Norte.

## Reglas de selección

- Se conserva una sola copia de cada archivo idéntico.
- Se priorizan modelos editables, archivos de fabricación y evidencias técnicas legibles.
- Los videos, fotografías completas y paquetes pesados se entregan mediante GitHub Releases.
- Se excluye material ajeno al sistema de estabilización y corrección activa de vuelo.
- La documentación vigente se distingue de borradores y revisiones históricas.
- No se publican entornos virtuales, cachés, resultados temporales ni binarios antiguos.

## Estado por área

| Área | Fuente | Destino | Estado |
| --- | --- | --- | --- |
| Diseño mecánico y CFD | Entrega técnica | `01-diseno-cad/` | Curado: 97 archivos en Git y 12 activos únicos reservados para Release |
| Electrónica | Entrega técnica | `02-electronica/` | Curado: 15 de 15 archivos incluidos |
| Firmware ESP32 | Área de trabajo local | `03-firmware-esp32/` | Completo: 3 sketches limpios y compilados |
| Aplicación | Área de trabajo local | `04-app-sultana/` | Completo: fuentes Python, C++, Go, configuraciones y datos |
| Documentación | Entrega técnica | `05-documentacion/` | Curada: 3 documentos en DOCX/PDF, arquitectura y manuales enlazados al código |
| Multimedia pesado | Entrega técnica | GitHub Release | Listo: 162 fotos/videos, 12 recursos CAD dinámicos y 1 BOM interactiva |

## Decisiones verificadas

### Diseño CAD y CFD

- La entrega contiene 126 archivos y 109 contenidos únicos por SHA-256.
- Se incluyeron en Git 97 contenidos únicos: modelo STL, plano complementario, renders y 72 resultados CFD.
- Doce contenidos dinámicos únicos —HTML, MP4 y ZIP— se reservaron para la Release.
- Se descartaron 17 copias exactas; entre ellas, los dos STL con nombres de revisión distintos resultaron idénticos.
- El detalle archivo por archivo se encuentra en [`01-diseno-cad/INVENTARIO.csv`](01-diseno-cad/INVENTARIO.csv).

### Electrónica

- Los 15 archivos entregados son distintos por SHA-256 y se conservaron.
- STEP, OBJ, MTL y BOM mantienen su formato original; las rutas públicas se normalizaron.
- El detalle se encuentra en [`02-electronica/INVENTARIO.csv`](02-electronica/INVENTARIO.csv).

### Software

- Se excluyeron entornos virtuales, cachés, resultados, compilaciones y ejecutables anteriores.
- La aplicación conserva 46 archivos Python, 5 C++, 107 de Kutta, 7 configuraciones y 31 recursos de datos.
- La identidad anterior fue eliminada de rutas, interfaz, protocolo propio y textos públicos.

### Documentación

- El reporte técnico final de 84 páginas se conserva como referencia integral vigente en DOCX y PDF verificado.
- El informe CAD se conserva como material complementario en ambos formatos.
- El protocolo de mayo de 2026 se conserva como revisión histórica y se advierte que no define el hardware ni el firmware vigentes.
- Cinco manuales anteriores con identidad heredada no se publican; sus instrucciones útiles se consolidaron en los README de firmware, electrónica y aplicación.
- El detalle y los hashes se encuentran en [`05-documentacion/INVENTARIO.csv`](05-documentacion/INVENTARIO.csv).

### Licencias

- Se conserva el texto MIT original del componente Kutta en [`LICENSES/Kutta-MIT.txt`](LICENSES/Kutta-MIT.txt).
- Las atribuciones y el estado de licencia del código propio se explican en [`THIRD_PARTY_NOTICES.md`](THIRD_PARTY_NOTICES.md).

## Paquetes cerrados para `v1.0.0`

| Activo | Tamaño aproximado | Estado |
|---|---:|---|
| Aplicación Windows portable | 413.15 MiB | ZIP verificado íntegramente |
| Aplicación Windows en un archivo | 410.27 MiB | Ejecutable abierto y revisado visualmente |
| Video principal ExpoCiencias 2026 | 686.29 MiB | Copia íntegra de la entrega seleccionada |
| Material técnico y multimedia | 876.62 MiB | ZIP verificado íntegramente; 175 archivos de material y 2 documentos guía |

Los cuatro activos están por debajo del límite de 2 GiB por archivo de GitHub Releases. Sus hashes finales se publican en `SHA256SUMS.txt` junto con la Release `v1.0.0`.

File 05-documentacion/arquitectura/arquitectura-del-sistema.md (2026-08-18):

# Arquitectura del sistema

Sultana del Norte distribuye la adquisición, el control, la telemetría y el análisis entre la aviónica embarcada y una estación terrestre.

```mermaid
flowchart LR
    subgraph Vehiculo["Vehículo experimental"]
        Sensores["BNO085 · BMP390 · GPS"] --> ESP32["ESP32-S3<br/>estimación y control"]
        ESP32 --> Seguridad["Interbloqueos y límites"]
        Seguridad --> Canards["4 actuadores / canards"]
        ESP32 --> Registro["Registro microSD"]
        ESP32 <--> RadioV["Radio nRF24L01"]
    end

    RadioV <--> RadioT["Estación terrestre ESP32-S3"]
    RadioT --> App["Aplicación Sultana del Norte"]
    App --> Telemetria["Telemetría y análisis"]
    App --> Simulacion["Simulación 6-DoF y trayectoria"]
    App --> CFD["Laboratorio CFD y túnel 2D"]
```

## Responsabilidades

| Componente | Responsabilidad principal | Fuente vigente |
|---|---|---|
| Firmware de vuelo | Leer sensores, estimar actitud, calcular órdenes, registrar y transmitir | [`03-firmware-esp32/control-de-vuelo/`](../../03-firmware-esp32/control-de-vuelo/) |
| Firmware de diagnóstico | Validar módulos y recorridos de actuadores en banco | [`03-firmware-esp32/diagnostico/`](../../03-firmware-esp32/diagnostico/) |
| Estación terrestre | Recibir radio y exponer telemetría rotulada | [`03-firmware-esp32/estacion-terrena/`](../../03-firmware-esp32/estacion-terrena/) |
| Aplicación Windows | Configurar escenarios, simular, visualizar y analizar | [`04-app-sultana/`](../../04-app-sultana/) |
| Electrónica | Interconexión física, alimentación, adquisición y actuación | [`02-electronica/`](../../02-electronica/) |
| Mecánica | Integración del módulo y geometría aerodinámica | [`01-diseno-cad/`](../../01-diseno-cad/) |

## Contratos importantes

- La dirección de radio propia del sistema es `SNL01` en ambos extremos.
- Los paquetes binarios de vuelo y las líneas de estación terrestre deben mantenerse compatibles.
- Los actuadores permanecen bloqueados por defecto hasta validar cableado, mezcla, sentidos y límites en banco.
- El pinout definido en firmware es la referencia de software. El esquema electrónico conserva discrepancias documentadas que requieren confirmación física antes de energizar actuadores.
- Los resultados CFD y HIL conservados son modelados o preliminares salvo que el documento indique explícitamente una medición experimental.

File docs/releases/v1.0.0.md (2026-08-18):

# Sultana del Norte v1.0.0

Primera publicación integral y curada del sistema de estabilización y corrección activa de vuelo de **Space NL**.

## Incluye

- diseño mecánico, modelo STL, renders y 72 resultados CFD organizados;
- esquemáticos, PCB, BOM interactiva y modelos electrónicos 3D;
- firmware de diagnóstico, vuelo y estación terrestre para ESP32-S3;
- código fuente completo de la aplicación Sultana del Norte en Python, C++ y Go;
- ejecutable único y paquete portable para Windows 10/11 x64;
- reporte técnico final, informe CAD y documentación de arquitectura;
- video principal, 162 fotografías/videos de evidencia y 12 recursos CAD dinámicos únicos.

## Descargas

| Archivo | Uso |
|---|---|
| `Sultana-del-Norte-v1.0.0-Windows-x64-portable.zip` | Opción recomendada: extraer y ejecutar `Sultana-del-Norte.exe` |
| `Sultana-del-Norte-v1.0.0-Windows-x64.exe` | Aplicación completa en un solo archivo |
| `Sultana-del-Norte-ExpoCiencias-2026.mp4` | Video principal del proyecto |
| `Sultana-del-Norte-v1.0.0-material-tecnico-y-multimedia.zip` | Evidencia fotográfica, videos, CAD dinámico y BOM interactiva |
| `SHA256SUMS.txt` | Sumas de verificación de todos los archivos anteriores |

## Verificación de esta versión

- aplicación Python: **112 pruebas superadas**;
- núcleo físico C++: **1/1 prueba CTest superada**;
- módulo aerodinámico Go: **todos los paquetes superados**;
- higiene e identidad del repositorio: **16 pruebas superadas**;
- los tres programas ESP32-S3 compilan correctamente y mantienen desactivadas las salidas de movimiento y despliegue por defecto;
- ambos formatos Windows fueron abiertos y revisados visualmente.

## Antes de usar

Los ejecutables no cuentan con firma digital comercial, por lo que Windows SmartScreen puede mostrar una advertencia de editor desconocido. Compara la suma SHA-256 de tu descarga con `SHA256SUMS.txt`.

La aplicación funciona sin Docker para simulación, mapas, telemetría y análisis. Docker Desktop solo es necesario para ejecutar casos externos de OpenFOAM.

> [!CAUTION]
> Es software experimental. Revisa el pinout contra el hardware real, conserva los seguros de actuación desactivados durante pruebas de banco y nunca conectes una carga de despliegue directamente a un GPIO.

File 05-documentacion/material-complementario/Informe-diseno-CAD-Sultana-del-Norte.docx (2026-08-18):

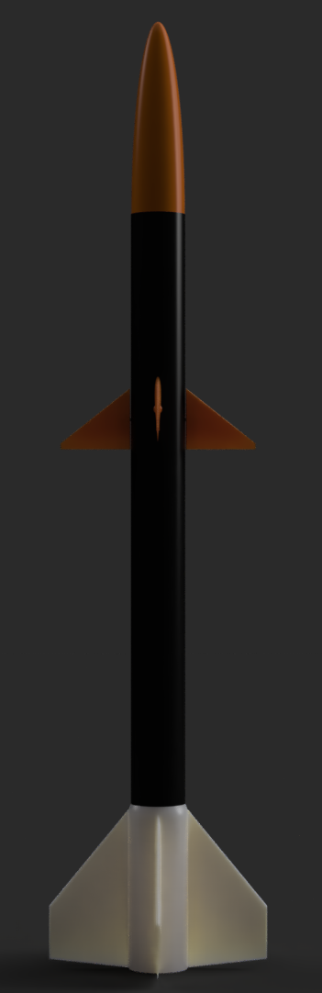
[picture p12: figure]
P1#y1

# Optimización Aerodinámica e Integración Mecánica del Sistema de Control Canard para el Cohete "Sultana del Norte"

# 1. Introducción y Planteamiento del Problema

El desarrollo de vehículos aeroespaciales experimentales requiere sistemas de estabilización y control direccional altamente precisos. Este proyecto se centra en el diseño, análisis aerodinámico e integración mecánica de un módulo de actuación canard para el cohete "Sultana del Norte" El objetivo principal radicó en lograr un control activo en dos ejes dentro de las severas restricciones volumétricas de un fuselaje de dos pulgadas de diámetro. Para asegurar que la solución propuesta poseyera un rigor técnico a la altura de una competencia nacional, la metodología empleada abarcó desde simulaciones balísticas para definir las condiciones de contorno, hasta dinámica de fluidos computacional (CFD) iterativa para perfeccionar la geometría de las superficies de control.

# 2. Perfil de Vuelo y Arquitectura Mecánica

El primer paso para el diseño del sistema consistió en comprender las exigencias cinemáticas a las que estaría sometido el vehículo. Utilizando el software OpenRocket, se simuló el perfil de vuelo integrando la masa, la longitud del fuselaje, la geometría de las ojivas y las aletas estabilizadoras pasivas. En esta fase final, se terminó de colocar los componentes definitivos que irán dentro del cohete, como los paracaídas del sistema de recuperación y el hardware del sistema electrónico, además de ajustar las opciones de empuje del motor. Esta simulación consolidada proyectó que el apogeo máximo se mantenga en 670 m y estableció una velocidad máxima de 142 m/s durante su fase propulsiva. Esta magnitud se estableció como el límite operativo fundamental para evaluar la resistencia estructural y predecir el comportamiento de la capa límite sobre los canards.

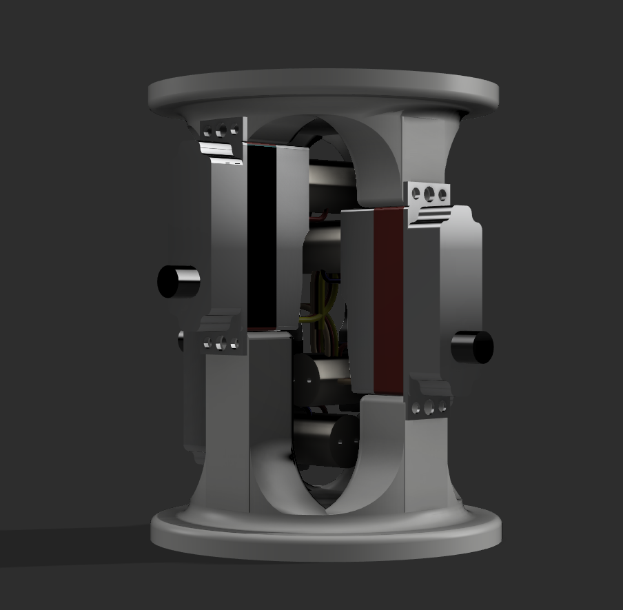
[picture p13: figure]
P7#y1

Resolver el empaquetamiento de los actuadores representó uno de los mayores desafíos de ingeniería del proyecto. El requerimiento de control de doble eje exigía la incorporación de cuatro servomotores independientes dentro de un espacio cilíndrico sumamente restringido. La solución adoptada consistió en un soporte interno altamente compacto que posiciona los ejes de rotación de forma simétrica transversalmente, pero introduce un desfase vertical intencional de 8 milímetros entre los pares de motores opuestos. Lejos de ser un defecto asimétrico, esta decisión de diseño actúa como un seguro mecánico crítico; garantiza que ni las superficies exteriores ni los mecanismos interiores colisionen al accionarse de manera simultánea. Adicionalmente, se modificó el punto de anclaje de las aletas movibles al servomotor para dotar al ensamble de una mayor resistencia estructural ante las cargas aerodinámicas. Además, esta densidad de empaquetamiento dota al módulo de una notable versatilidad, permitiendo su futura integración en fuselajes aún más esbeltos de hasta 1.5 pulgadas.

# 3. Justificación de la Configuración Cruciforme (4 Aletas)

Una de las decisiones arquitectónicas más importantes fue la adopción de un sistema cruciforme (cuatro aletas) en lugar de una configuración triforme (tres aletas) o monowing (dos aletas). Si bien un arreglo de tres aletas ofrece ventajas en términos de peso reducido y menor arrastre frontal, introduce una complejidad computacional masiva para el piloto automático (autopilot). En una configuración triforme, el control de los ejes de cabeceo (pitch), guiñada (yaw) y alabeo (roll) está fuertemente acoplado, requiriendo que múltiples aletas actúen de forma asimétrica y coordinada para lograr un movimiento en un solo eje.

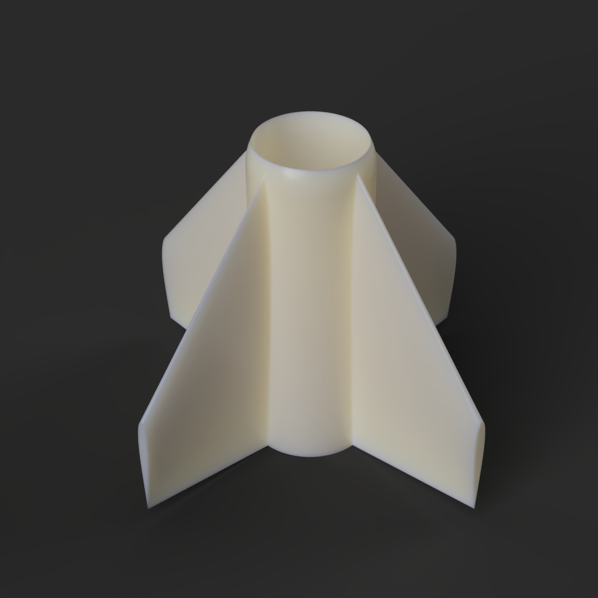
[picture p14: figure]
P10#y1

Por el contrario, la configuración cruciforme en orientación "+" o "x" permite desacoplar los ejes de control de manera ortogonal. Esto significa que un par de aletas opuestas controla exclusivamente el cabeceo, mientras que el otro par perpendicular controla independientemente la guiñada. Esta ortogonalidad simplifica drásticamente el algoritmo de estabilización del cohete, incrementa la efectividad del control direccional a velocidades supersónicas y transónicas, y garantiza una redundancia mecánica donde el vehículo mantiene autoridad de vuelo predecible incluso bajo turbulencias asimétricas.

# 4. Metodología de Actuación y Control Dinámico

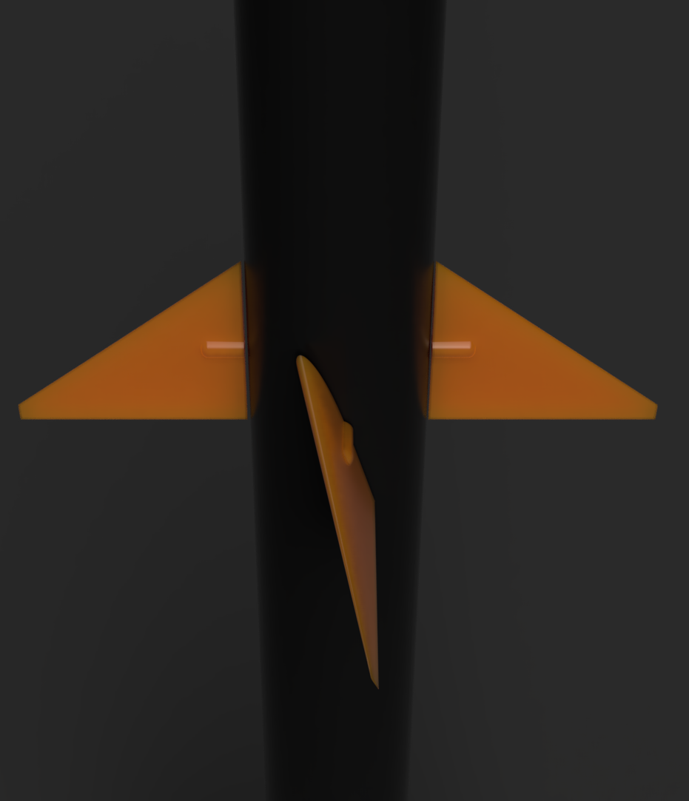
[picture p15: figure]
P13#y1

Desde la perspectiva del accionamiento aerodinámico, el diseño evolucionó hacia una configuración de rotación pivotante (canards all-moving), inspirada profundamente en la filosofía de control y estabilización de los misiles tácticos. A diferencia de las iteraciones iniciales basadas en cinemática de flaps, esta arquitectura definitiva emplea un perfil alar sumamente delgado diseñado para cortar el flujo transónico minimizando la resistencia parásita frontal (drag). La integración mecánica se resolvió mediante un robusto anclaje circular posicionado en la región central de la aleta. La fundamentación técnica detrás de esta decisión radica en acercar el eje de rotación al centro de presión hidrodinámico, lo cual equilibra las cargas aerodinámicas y reduce drásticamente el esfuerzo de torque exigido a los servomotores. Operativamente, para mantener la estabilidad del flujo y evitar una separación turbulenta (stall) que actúe como freno direccional severo, el sistema fue restringido mecánica y lógicamente a un rango de movimiento máximo de 20°. Las simulaciones CFD respaldan que esta configuración centralizada maximiza la autoridad direccional en su rango operativo útil, simplifica enormemente la manufactura y mitiga los puntos de falla bajo los regímenes de alta vibración inducidos por el motor

# 5. Evolución Aerodinámica Iterativa

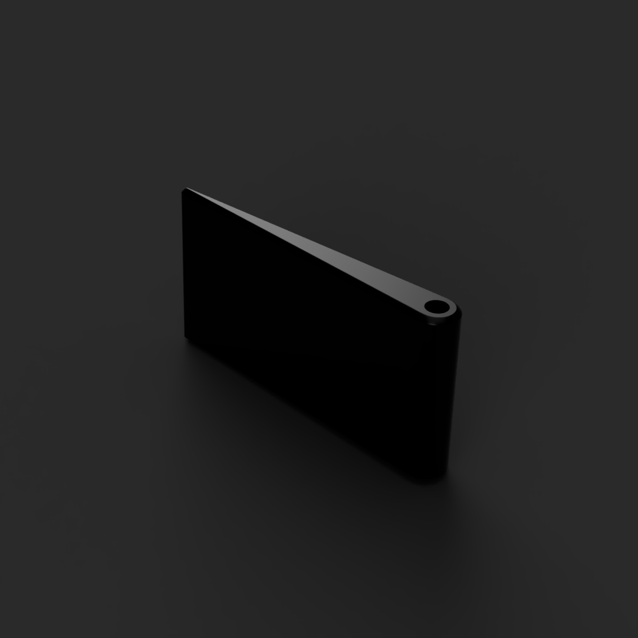
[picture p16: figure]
P15#y1

Comprendiendo que el diseño aeroespacial rara vez alcanza el óptimo en su primera etapa, se estructuró un análisis iterativo basado en los resultados obtenidos de simulación. La primera iteración evaluó un perfil de aleta predominantemente plano. Empíricamente, este diseño actuó como una barrera agresiva contra el flujo, generando una notable fuerza lateral, pero induciendo simultáneamente una separación turbulenta que se tradujo en un drag prohibitivo.

Buscando mitigar este arrastre parásito, se analizaron perfiles simétricos empleados en misiles tácticos y aviación de alta velocidad, como las series NACA y el RAE 100, utilizando herramientas de evaluación polar (Airfoil Tools). La segunda iteración adoptó uno de estos perfiles hidrodinámicos. No obstante, las pruebas CFD revelaron que la búsqueda excesiva de un bajo coeficiente de resistencia comprometió la efectividad del control, generando un área de presión insuficiente y reduciendo la fuerza direccional a niveles subóptimos.

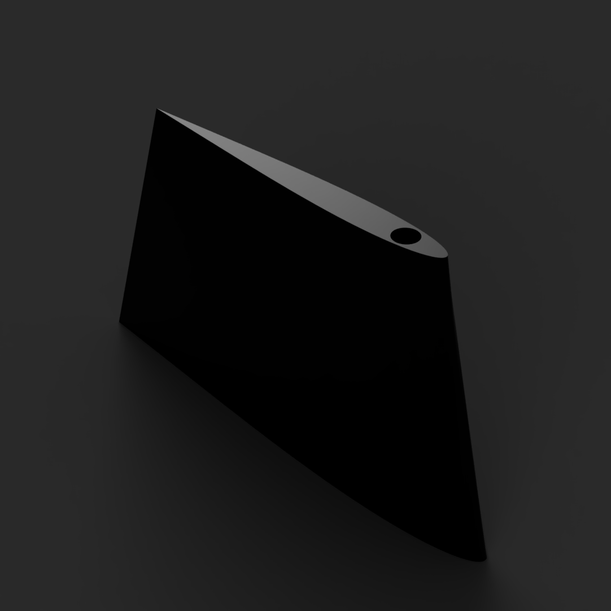
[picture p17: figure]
P17#y1

La tercera iteración nació como una respuesta de síntesis a estos hallazgos. Se desarrolló una geometría híbrida que combinó el área proyectada extendida del primer modelo con el contorno aerodinámico del segundo. Esta hibridación permitió que el flujo de aire se mantuviera adherido a la superficie por más tiempo, retrasando el fenómeno de entrada en pérdida (stall) y capitalizando sobre la sustentación.

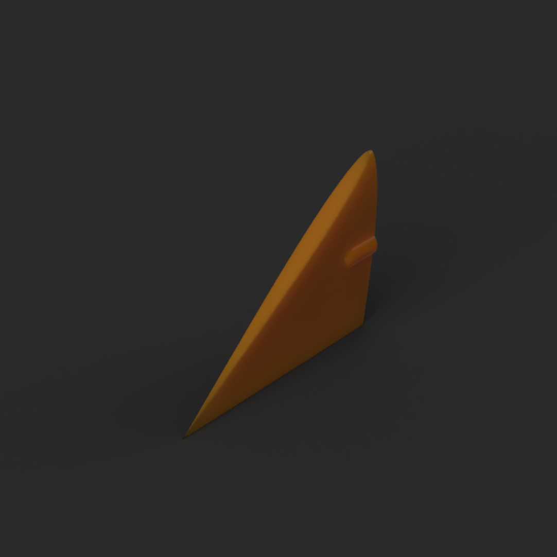
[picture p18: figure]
P18#y1

Buscando simplificar aún más la manufactura, se desarrolló una cuarta iteración realizando unas aletas similares a los misiles balísticos, manteniendo una filosofía diferente a la utilizada anteriormente. Se diseñó con un ángulo de 45° de ataque, manteniendo una línea recta al final de la cuerda del perfil, y se utilizó exactamente el mismo perfil aerodinámico de las aletas estabilizadoras inferiores del cohete (NACA 1940). Además, fue acompañada mecánicamente con un límite de deflexión máximo de 20°. Sin embargo, debido a que el modelado CAD se realizó simplemente mediante una extrusión del perfil alar y un corte directo a 45°, el diseño causaba una severa inestabilidad aerodinámica a partir de los ángulos de ataque comprendidos entre los 15° y 22°.

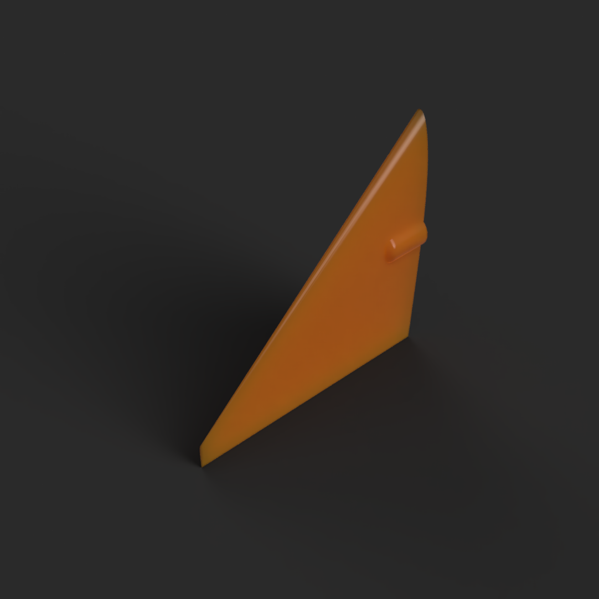
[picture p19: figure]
P19#y1

Para solucionar este problema, se optó por realizar una quinta iteración (Aleta 4 Corregida) mediante una solevación (lofting) de dos perfiles idénticos. Esta técnica permitió mantener las dimensiones generales y el agresivo ángulo de ataque de 45°, pero logrando un redondeo orgánico esencial para mantener la estabilidad del flujo de aire sobre la superficie aerodinámica. Esta corrección dio resultados sumamente positivos: mejoró el Downforce (fuerza lateral), redujo sustancialmente el Drag (resistencia) y arrojó una gráfica de ángulo-fuerza perfectamente estable y predecible.

P20#y1

# 6. Análisis CFD en Escenario Crítico: Viento Cruzado Adverso

Para validar el diseño final antes de su implementación física, las simulaciones no se limitaron a escenarios ideales. Se ejecutaron pruebas CFD con las condiciones ambientales reales proyectadas para el día de la prueba, el 8 de agosto: temperatura ambiente de 30 °C (303.15 K), humedad relativa del 50%, y ráfagas de viento cruzado de 20 km/h (5.55 m/s).

Para llevar la evaluación al límite de sus capacidades operativas (Worst-Case Scenario), la simulación se configuró explícitamente para que este viento lateral chocara en la dirección contraria a la que se quería desviar el cohete. A pesar de que el viento incidente generaba un empuje opuesto masivo, las pruebas demostraron la excepcional eficiencia de la aleta solevada en sus primeros 15° a 20° de actuación. La superficie de control fue capaz de generar aproximadamente 30 N de sustentación lateral neta, logrando vencer completamente la carga atmosférica adversa y garantizando la autoridad del vehículo sobre su trayectoria.

P24#yIS1

# 7. Modelado Matemático y Análisis Comparativo

Para dotar al proyecto de un respaldo analítico escalable, los datos discretos de las simulaciones CFD de cada aleta fueron procesados matemáticamente. Se emplearon regresiones polinomiales y de splines cúbicos para modelar con precisión la curva de fuerza a lo largo de los grados de rotación, capturando el pico de sustentación direccional y el colapso por stall. Se desarrolló un sistema de predicción universal en Excel que aplica el principio de proporcionalidad dinámica, permitiendo predecir la fuerza exacta para cualquier ángulo y velocidad.

# 8. Selección de Materiales y Análisis de Esfuerzos Estructurales

La viabilidad de las superficies de control no solo depende de su eficiencia aerodinámica, sino también de su integridad mecánica bajo cargas dinámicas críticas. Para la manufactura de los canards, se seleccionó Ácido Poliláctico (PLA) utilizando tecnología de manufactura aditiva por deposición de material fundido (FDM). Contar con la capacidad de gestionar la impresión 3D de manera interna no solo acelera la iteración rápida de prototipos durante la fase de diseño, sino que asegura una transición directa hacia la manufactura de medianas producciones o módulos de repuesto con total autonomía operativa. El PLA ofrece un excelente equilibrio entre alta rigidez estructural, bajo peso y precisión dimensional, características vitales para mantener la fidelidad del perfil aerodinámico híbrido durante el vuelo.

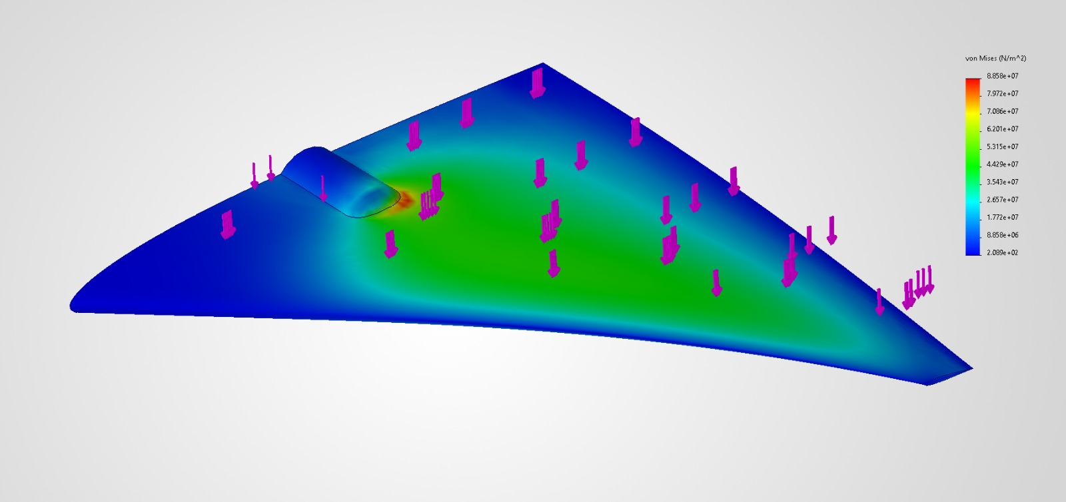
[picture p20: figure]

Para validar empíricamente que el material polimérico soportaría las fuerzas direccionales extremas calculadas en la simulación, se sometió el modelo CAD definitivo a un Análisis de Elementos Finitos (FEA). Se aplicó una matriz de carga distribuida a lo largo del perfil de la aleta, emulando la presión dinámica del flujo de aire transónico incidente, y se definió el eje de rotación del servomotor como la restricción geométrica (punto de anclaje).

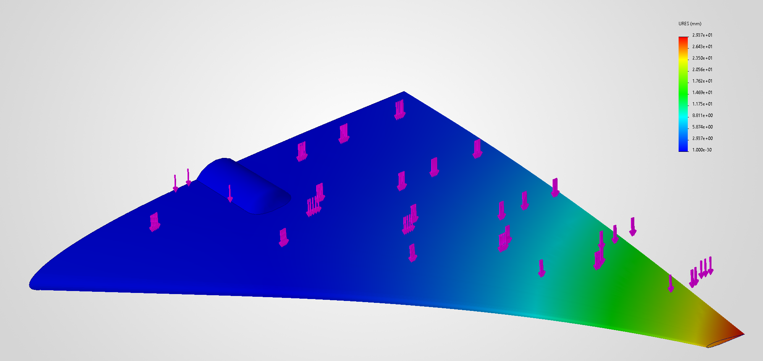
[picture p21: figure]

Los resultados de la simulación de Tensión de Von Mises y Deformación Equivalente evidencian el comportamiento estructural del ensamble. Como se observa en los gradientes térmicos, la concentración de esfuerzos se localiza predominantemente en la raíz del eje de anclaje, indicando que el punto pivote absorbe exitosamente el torque máximo sin transferir estrés crítico al resto de la aleta. El cuerpo principal del canard se mantiene en zonas de bajo estrés, garantizando que no se superará el límite elástico del material. Finalmente, la flexibilidad inherente del PLA extruido actúa como un amortiguador estructural frente a ráfagas de aire, confirmando que la pieza mantiene amplios márgenes de seguridad.

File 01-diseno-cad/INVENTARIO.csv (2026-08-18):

origen_relativo | destino_relativo | bytes | sha256 | estado | nota
DISEÑO 3D\Extra\SNL-220-01 (2).pdf | 01-diseno-cad\material-complementario\plano-motor-knsb-snl-220-01.pdf | 348995 | E4BA56619235488BD9E29C3F7439E1493221A27651E1FEE3752F99012845285B | incluido_en_git | Plano de propulsión complementario; no forma parte del control activo
DISEÑO 3D\Extra\Ensamble (versión FINAL CORREGIDA EN BASE AL NACA).stl | 01-diseno-cad\modelos\sultana-del-norte-final-naca.stl | 2491084 | D81434E7AD33A059F55FB67FD0851A4AFFF841BB18453B16E8A0A0EB2F696FF2 | incluido_en_git | Modelo final; idéntico por hash al STL de validación
DISEÑO 3D\Img_Doc\Aletas_movibles_2_2026-Aug-03_10-26-20AM-000_CustomizedView24306284595.png | 01-diseno-cad\renders\aletas-moviles.png | 76096 | 97D59BF0DD689B9CC885301B0BBD1FBBDDFFC6C3312ED7648C5E3EA85DD7F798 | incluido_en_git | Render o evidencia de diseño seleccionada
DISEÑO 3D\Img_Doc\Aletas_v3_2026-Aug-03_10-25-53AM-000_CustomizedView24889502668.png | 01-diseno-cad\renders\aletas-v3.png | 63396 | E172F44A896C04C66995FCD47117EA4E38081B3CF960FB19B189F924D0802077 | incluido_en_git | Render o evidencia de diseño seleccionada
DISEÑO 3D\Img_Doc\qaewrfwqfteqwg.png | 01-diseno-cad\renders\captura-analisis-cad.png | 223525 | F581665285ACEF162450F916B4D69A6DC99A9F760796B414415172CF971562A7 | incluido_en_git | Render o evidencia de diseño seleccionada
DISEÑO 3D\Img_Doc\Captura de pantalla 2026-08-09 023957.png | 01-diseno-cad\renders\captura-cad-01.png | 47739 | B6B4F396160FB1813D5875FD6D2BA8BE55931B1338A9872FE527ADBFE718FF5C | incluido_en_git | Render o evidencia de diseño seleccionada
DISEÑO 3D\Img_Doc\Captura de pantalla 2026-08-10 014944.png | 01-diseno-cad\renders\captura-cad-02.png | 445387 | 85300854A150A9B53E4EA0846562AC664D1A7BC9D7DA0446A32CBC39C5D673C7 | incluido_en_git | Render o evidencia de diseño seleccionada
DISEÑO 3D\Img_Doc\Captura de pantalla 2026-08-10 015124.png | 01-diseno-cad\renders\captura-cad-03.png | 403508 | D37170B9B883BF33DB1B1B2E2A8374C4C70D07508FD3681AC3EACBF5CC2B63D6 | incluido_en_git | Render o evidencia de diseño seleccionada
DISEÑO 3D\Img_Doc\Comparativa_5_Aletas_20grados.png | 01-diseno-cad\renders\comparativa-aletas-20-grados.png | 233643 | A30D4DFBC9E203C14E0F806C4F95DF2054BA3376338E918B99ADE08840438449 | incluido_en_git | Render o evidencia de diseño seleccionada
DISEÑO 3D\Img_Doc\Comparativa_Viento_Adverso.png | 01-diseno-cad\renders\comparativa-viento-adverso.png | 190400 | B93F108151AA22390ED9E87802C6BFD7ADF4C342EE33F141EDD1822F1C8E403F | incluido_en_git | Render o evidencia de diseño seleccionada
DISEÑO 3D\Img_Doc\a14a20b0-a5d2-491b-9090-8d9ba845c551.PNG | 01-diseno-cad\renders\detalle-canards-01.png | 227646 | CFC12AB3A433D1FF97DF07AF674D5ED213D161E805872F6C6D5E5143856F9681 | incluido_en_git | Render o evidencia de diseño seleccionada
DISEÑO 3D\Img_Doc\d9d912a1-a6be-426d-b33b-d932e41537a7.PNG | 01-diseno-cad\renders\detalle-canards-02.png | 80610 | FEB238F3BA800A753ECCC9F611E2FEEBBA346CCC2BF6B234AEFEE2B261E93678 | incluido_en_git | Render o evidencia de diseño seleccionada
DISEÑO 3D\Img_Doc\Ensamble_todo_2026-Aug-03_10-01-46AM-000_CustomizedView24358796562.png | 01-diseno-cad\renders\ensamble-completo.png | 174208 | A2FD24016B1BC83828233C19E9C85B792E83CEE09917DC94AB695C9A8227E0CC | incluido_en_git | Render o evidencia de diseño seleccionada
DISEÑO 3D\Img_Doc\Ensamble todo v1.png | 01-diseno-cad\renders\ensamble-v1.png | 235234 | 3DB466B152F6AC6FD70E7F27BE8D60852D94F8E564C91A3E04A8E2AA3CD8A174 | incluido_en_git | Render o evidencia de diseño seleccionada
DISEÑO 3D\Img_Doc\Ensamble todo v1A.png | 01-diseno-cad\renders\ensamble-v1a.png | 267720 | 47BD1519025AE51624A75AD5369C9188AA1F002E2D487F225606856F497783F0 | incluido_en_git | Render o evidencia de diseño seleccionada
DISEÑO 3D\Img_Doc\Ensamble_(versin_de_validacin)_2026-Aug-09_09-51-00AM-000_CustomizedView27181243055.png | 01-diseno-cad\renders\ensamble-validacion-vista-01.png | 74784 | 59C00CED8B01A1C6B3DB97065BF9344D220765CFF782EF6BAB8BC7B3A893B5CC | incluido_en_git | Render o evidencia de diseño seleccionada
DISEÑO 3D\Img_Doc\Ensamble_(versin_de_validacin)_2026-Aug-09_09-51-33AM-000_CustomizedView48707317181.png | 01-diseno-cad\renders\ensamble-validacion-vista-02.png | 75386 | 0AF71E074D0B46CA84FCAF73FF1871884F58B3420EBEAFF49FD121D1EA3582BD | incluido_en_git | Render o evidencia de diseño seleccionada
DISEÑO 3D\Img_Doc\Ensamble_(versin_de_validacin)_2026-Aug-09_09-52-05AM-000_CustomizedView14069356933.png | 01-diseno-cad\renders\ensamble-validacion-vista-03.png | 97237 | 480B85548B46480E9FAA8296A86077856B0263D5B38C588564F2BEC9E8BA0AB1 | incluido_en_git | Render o evidencia de diseño seleccionada
DISEÑO 3D\Img_Doc\Ensamble_(versin_de_validacin)_2026-Aug-09_09-52-54AM-000_CustomizedView25760274848.png | 01-diseno-cad\renders\ensamble-validacion-vista-04.png | 140534 | 9068017820AD800C9796F2308561E906ECBC6F43A2CAF0D8A0E159FE5D89030E | incluido_en_git | Render o evidencia de diseño seleccionada
DISEÑO 3D\Img_Doc\Ensamble_(versin_de_validacin)_2026-Aug-09_11-58-14PM-000_CustomizedView11922554831.png | 01-diseno-cad\renders\ensamble-validacion-vista-05.png | 118314 | 0B0BC7B8E4E4284A868C2DF8BC175D9873A2F00E024F680F29BECD626F35ADE4 | incluido_en_git | Render o evidencia de diseño seleccionada
DISEÑO 3D\Img_Doc\Ensamble_(versin_de_validacin)_2026-Aug-10_12-00-43AM-000_CustomizedView10826954976.png | 01-diseno-cad\renders\ensamble-validacion-vista-06.png | 139007 | 472198EF7335B51AA405D61D533587DE7FF782EF6A37AC3B6D7DD0FCAABE679F | incluido_en_git | Render o evidencia de diseño seleccionada
DISEÑO 3D\Img_Doc\Openrocket Grafica.png | 01-diseno-cad\renders\simulacion-openrocket.png | 122354 | 0E8BC0A1E6AA8E8AB591130FF93983E0FD556A84DEA54982288F227A8D918156 | incluido_en_git | Render o evidencia de diseño seleccionada
DISEÑO 3D\Img_Doc\Sin_ttulo_2026-Aug-03_10-29-32AM-000_CustomizedView25921842192.png | 01-diseno-cad\renders\vista-ensamble-canards.png | 69176 | 2EAEE3330980113F30529C9315B209E982976B751665D421CFB1FE5E38ADB3C2 | incluido_en_git | Render o evidencia de diseño seleccionada
DISEÑO 3D\Img_CFD\All 171 Irl Cond\0° 171 Irl Cond\0 171 TB_1.png | 01-diseno-cad\simulacion-cfd\condiciones-reales-171-ms\angulo-00\resultado-01.png | 155114 | 0AC0C88DE86F23ADAE17AF0F41A1E0687ACCB6DB13EBD69888862A9F062B34B6 | incluido_en_git | Resultado CFD conservado con condición y ángulo normalizados
DISEÑO 3D\Img_CFD\All 171 Irl Cond\0° 171 Irl Cond\0 171 TB_2.png | 01-diseno-cad\simulacion-cfd\condiciones-reales-171-ms\angulo-00\resultado-02.png | 315837 | B47FE5BA83633125FD987F1767A24AA762512812BD803E22EEEA7CC0D41511AC | incluido_en_git | Resultado CFD conservado con condición y ángulo normalizados
DISEÑO 3D\Img_CFD\All 171 Irl Cond\0° 171 Irl Cond\0 171 TB_3.png | 01-diseno-cad\simulacion-cfd\condiciones-reales-171-ms\angulo-00\resultado-03.png | 378158 | CC8B253EE05ECAE5C0141CD61D8821A03F71F721B89AEA0655415AA0F80BAD29 | incluido_en_git | Resultado CFD conservado con condición y ángulo normalizados
DISEÑO 3D\Img_CFD\All 171 Irl Cond\0° 171 Irl Cond\0 171 TB_4.png | 01-diseno-cad\simulacion-cfd\condiciones-reales-171-ms\angulo-00\resultado-04.png | 341036 | 22A66608A2C8ED3288D19A67142D879FAEE8F40C7CE6B1C9B75CD228821DCB9F | incluido_en_git | Resultado CFD conservado con condición y ángulo normalizados
DISEÑO 3D\Img_CFD\All 171 Irl Cond\0° 171 Irl Cond\0 171 TB.png | 01-diseno-cad\simulacion-cfd\condiciones-reales-171-ms\angulo-00\resultado-05.png | 60751 | AC7CB2452AEE1E8563D91B0C0A463E4771A5F16CB257D80E6C2F2567EC18B682 | incluido_en_git | Resultado CFD conservado con condición y ángulo normalizados
DISEÑO 3D\Img_CFD\All 171 Irl Cond\5° 171 Irl Cod\5 171(1)_1.png | 01-diseno-cad\simulacion-cfd\condiciones-reales-171-ms\angulo-05\resultado-01.png | 150734 | F7E800378BBF1664AEA952FACAB83633ABB3C31F5F27C3C16874571EEAA37DA3 | incluido_en_git | Resultado CFD conservado con condición y ángulo normalizados
DISEÑO 3D\Img_CFD\All 171 Irl Cond\5° 171 Irl Cod\5 171(1)_2.png | 01-diseno-cad\simulacion-cfd\condiciones-reales-171-ms\angulo-05\resultado-02.png | 317936 | F0E5630092895B03D40777B135359C454D4DCE37E3E4F08290E00D030EBA30E7 | incluido_en_git | Resultado CFD conservado con condición y ángulo normalizados
DISEÑO 3D\Img_CFD\All 171 Irl Cond\5° 171 Irl Cod\5 171(1)_3.png | 01-diseno-cad\simulacion-cfd\condiciones-reales-171-ms\angulo-05\resultado-03.png | 358590 | 44242D1F10F4E5CB9216B408E7D54740A24CAC3B037B804D4D5B37FA49A08404 | incluido_en_git | Resultado CFD conservado con condición y ángulo normalizados
DISEÑO 3D\Img_CFD\All 171 Irl Cond\5° 171 Irl Cod\5 171(1)_4.png | 01-diseno-cad\simulacion-cfd\condiciones-reales-171-ms\angulo-05\resultado-04.png | 255311 | 978E04FABD7D7CBEE37C88FB96C0CF0484FCEEE16FCA5084690B9CAC70C26943 | incluido_en_git | Resultado CFD conservado con condición y ángulo normalizados
DISEÑO 3D\Img_CFD\All 171 Irl Cond\5° 171 Irl Cod\5 171(1)_5.png | 01-diseno-cad\simulacion-cfd\condiciones-reales-171-ms\angulo-05\resultado-05.png | 367514 | 53D2C1E8B5088FE8BC854517D0154C653AF6C046AA21133144754E8BB89317F0 | incluido_en_git | Resultado CFD conservado con condición y ángulo normalizados
DISEÑO 3D\Img_CFD\All 171 Irl Cond\5° 171 Irl Cod\5 171(1).png | 01-diseno-cad\simulacion-cfd\condiciones-reales-171-ms\angulo-05\resultado-06.png | 50365 | 74B22703A439F7F9D70668B08DFD9321365BEBA03ED80B7D5EE302067E1537A7 | incluido_en_git | Resultado CFD conservado con condición y ángulo normalizados
DISEÑO 3D\Img_CFD\All 171 Irl Cond\10° 171 Irl Cond\10 171(1)_1.png | 01-diseno-cad\simulacion-cfd\condiciones-reales-171-ms\angulo-10\resultado-01.png | 49702 | 2BA4BCABF622796906FF33C7AF018F0C8173D7B7140A58EF6E0778B86F0944A7 | incluido_en_git | Resultado CFD conservado con condición y ángulo normalizados
DISEÑO 3D\Img_CFD\All 171 Irl Cond\10° 171 Irl Cond\10 171(1)_2.png | 01-diseno-cad\simulacion-cfd\condiciones-reales-171-ms\angulo-10\resultado-02.png | 125582 | 6BF5AC8E6CFA68D72B212E49471FC7027AA3D9D83A5D904D93C9CCE0E5CB16FB | incluido_en_git | Resultado CFD conservado con condición y ángulo normalizados
DISEÑO 3D\Img_CFD\All 171 Irl Cond\10° 171 Irl Cond\10 171(1)_3.png | 01-diseno-cad\simulacion-cfd\condiciones-reales-171-ms\angulo-10\resultado-03.png | 288991 | 8B3C2FBF8E9A00AE49B79B0855871811F62A5EB3446F6D6771FB59BE27E54A83 | incluido_en_git | Resultado CFD conservado con condición y ángulo normalizados
DISEÑO 3D\Img_CFD\All 171 Irl Cond\10° 171 Irl Cond\10 171(1)_4.png | 01-diseno-cad\simulacion-cfd\condiciones-reales-171-ms\angulo-10\resultado-04.png | 325247 | 68A3580F00075AAC1687FC941E468D45DF4A302BC28C5CE7AE2E2FDAC3847AC5 | incluido_en_git | Resultado CFD conservado con condición y ángulo normalizados
DISEÑO 3D\Img_CFD\All 171 Irl Cond\10° 171 Irl Cond\10 171(1)_5.png | 01-diseno-cad\simulacion-cfd\condiciones-reales-171-ms\angulo-10\resultado-05.png | 399132 | CCB3566E9372198FE85D60C98EECD4113C6FA7CF1170A926B56A5C3A1A03A756 | incluido_en_git | Resultado CFD conservado con condición y ángulo normalizados
DISEÑO 3D\Img_CFD\All 171 Irl Cond\10° 171 Irl Cond\10 171(1)_6.png | 01-diseno-cad\simulacion-cfd\condiciones-reales-171-ms\angulo-10\resultado-06.png | 348009 | 333FDE443CE166073A19C710A99541F2691A41B53AE2D150A4563C82512B5C9B | incluido_en_git | Resultado CFD conservado con condición y ángulo normalizados
DISEÑO 3D\Img_CFD\All 171 Irl Cond\10° 171 Irl Cond\10 171(1).png | 01-diseno-cad\simulacion-cfd\condiciones-reales-171-ms\angulo-10\resultado-07.png | 55060 | 50CA39CCC7435AC348BBE71BF5452D8A83A232AFFFB432E2DA9D5E63744D4D55 | incluido_en_git | Resultado CFD conservado con condición y ángulo normalizados
DISEÑO 3D\Img_CFD\All 171 Irl Cond\15° 171 Irl Cond\15 171(1)_1.png | 01-diseno-cad\simulacion-cfd\condiciones-reales-171-ms\angulo-15\resultado-01.png | 72650 | B3E7309432385A36D648546A15AF3DE8C16E2C6EB7D5C66BB059F851EAE1B85C | incluido_en_git | Resultado CFD conservado con condición y ángulo normalizados
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

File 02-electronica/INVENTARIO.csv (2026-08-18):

origen_relativo | destino_relativo | bytes | sha256 | estado | nota
Electronica\InteractiveBOM_PCB1_2026-8-10.html | 02-electronica\bom\interactive-bom.html | 20334354 | F2E01A142CA0799F8F3221280E7E33EE1F95AAE9B7ACA12BF04EB808D33ACED3 | incluido_en_git | Lista de materiales interactiva
Electronica\SCH_Schematic1_1-P1_2026-08-10.png | 02-electronica\esquematicos\esquematico-sultana.png | 495033 | 1DF7E97D10397D5FC5B7686757A52760E997CF53E637BF6315AD83383A210799 | incluido_en_git | Esquemático raster
Electronica\SCH_Schematic1_1-P1_2026-08-10.svg | 02-electronica\esquematicos\esquematico-sultana.svg | 230715 | 44E7B2061D03E024C86D4C4ED9BE9B25EDD651458D8AEA8C763365767B5431E7 | incluido_en_git | Esquemático vectorial
Electronica\PCB_EXPOCIENCIAS.mtl | 02-electronica\modelos-3d\pcb-sultana.mtl | 5848 | 49887B7BBB9FF1EE9289E23E534A9803042E4BDA8FDE0A089B3F4F6DE6F3C085 | incluido_en_git | Material del modelo OBJ
Electronica\PCB_EXPOCIENCIAS.obj | 02-electronica\modelos-3d\pcb-sultana.obj | 10921443 | 2868F5FD0EA046CADBEF27035E673459C60424C8DEFDD06E5835E66BE8CBA8A5 | incluido_en_git | Modelo OBJ de PCB
Electronica\3D PCB EXPOCIENCIAS.step | 02-electronica\modelos-3d\pcb-sultana.step | 24699052 | 826C3915E76CECB76CA9EC7F1A1474A44319F46C5D6E34130B9DDB4A7CCF3485 | incluido_en_git | Modelo STEP de PCB
Electronica\Captura de pantalla 2026-08-10 212159.png | 02-electronica\pcb\captura-editor-pcb.png | 36961 | 5B2FDA7B98A94682CA216AB5A39DB525C30026F6968FC70912FFE167CD0C0197 | incluido_en_git | Captura del diseño electrónico
Electronica\2D_PCB1_2026-08-10 (1).png | 02-electronica\pcb\pcb-2d-vista-01.png | 307887 | 5FE250433AF395DF58F3486F9AC614E878F39B4CD7F96469456E5FE0AF0C17CA | incluido_en_git | Vista 2D de PCB
Electronica\2D_PCB1_2026-08-10.png | 02-electronica\pcb\pcb-2d-vista-02.png | 274425 | 3B2C118F61E64C78655CB16979A1DAAF87B1C0CF88E325CB6FF1917BCB4D727C | incluido_en_git | Vista 2D alternativa de PCB
Electronica\3D_PCB1_2026-08-10 (1).png | 02-electronica\pcb\pcb-3d-vista-01.png | 401623 | F4FC29314C955B0360E96B431875A262E0D265343F733DA393633F5B95CBF54E | incluido_en_git | Render 3D de PCB
Electronica\3D_PCB1_2026-08-10 (2).png | 02-electronica\pcb\pcb-3d-vista-02.png | 323129 | 69A912DFCE277D8236716A826A8B47425D5236E1B763205E13774565316B9CBA | incluido_en_git | Render 3D de PCB
Electronica\3D_PCB1_2026-08-10.png | 02-electronica\pcb\pcb-3d-vista-03.png | 254404 | 9A57CD6BB667CB0EB1241DEDA445A86A5CD77E10FD2A61BB4C025253EDC03363 | incluido_en_git | Render 3D de PCB
Electronica\PCB_PCB1_2026-08-10.png | 02-electronica\pcb\pcb-layout.png | 780377 | 9265C47A23C3B12C24923877E6CEC775080A0FD02D58E437FE23FC5B8D42BB3D | incluido_en_git | Layout de PCB
Electronica\1aa54170-1731-42c8-99f5-4e1365d63c22-removebg-preview.png | 02-electronica\recursos\space-nl.png | 247605 | 0B70FD5AC562FC474EC389849C018FAEBC52D409F442D9B75F91757AF3BA9A8E | incluido_en_git | Recurso raster de identidad
Electronica\1aa54170-1731-42c8-99f5-4e1365d63c22-removebg-preview (2).svg | 02-electronica\recursos\space-nl.svg | 498755 | EAFF7C6B8B3469F27E4738E6E1009631B02EB2B93925738F97B281E3A63E63D7 | incluido_en_git | Recurso vectorial de identidad

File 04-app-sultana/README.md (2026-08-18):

# Aplicación Sultana del Norte

Aplicación de escritorio para simulación 6-DoF, cálculo de trayectoria, telemetría, análisis CFD y visualización del vehículo de Sultana del Norte.

## Funciones principales

- Simulación tridimensional de vuelo y trayectoria.
- Configuración del vehículo, entorno, masa y curva de empuje.
- Importación de proyectos OpenRocket.
- Telemetría serie y análisis de datos recibidos.
- Ensayos CFD mediante OpenFOAM cuando Docker está disponible.
- Túnel de viento 2D cualitativo basado en Kutta.
- Monte Carlo, clima, terreno y exportación de resultados.

## Organización

| Ruta | Contenido |
| --- | --- |
| [`python/`](python/) | Interfaz PySide6, servicios y pruebas |
| [`cpp/`](cpp/) | Núcleo físico C++ y enlace para Python |
| [`kutta/`](kutta/) | Túnel de viento 2D en Go, bajo licencia MIT |
| [`configs/`](configs/) | Vehículos, entornos y escenarios reproducibles |
| [`data/`](data/) | Modelos 3D, calibración y tablas preliminares |
| [`run_all.py`](run_all.py) | Preparación y verificación integral |
| [`build_exe.py`](build_exe.py) | Construcción del ejecutable Windows |

## Descargar la aplicación

La versión lista para Windows se publica en [GitHub Releases](https://github.com/aurelioasu/Sistema-de-Estabilizaci-n-Activa-y-c-lculo-de-trayectoria-Sultana-del-Norte-BY-SPACENL/releases/latest).

Descargas previstas para `v1.0.0`:

- `Sultana-del-Norte-v1.0.0-Windows-x64.exe`
- `Sultana-del-Norte-v1.0.0-Windows-x64-portable.zip`

El binario no cuenta con firma digital comercial. Windows puede mostrar una advertencia de SmartScreen; verifica primero la suma SHA-256 publicada en la misma Release.

## Ejecutar desde el código fuente

Requisitos recomendados:

- Windows 10/11 x64;
- Python 3.11 o posterior;
- Visual Studio 2022 Build Tools con C++;
- CMake 3.24 o posterior;
- Docker Desktop únicamente para ejecutar casos OpenFOAM.

```powershell
python -m venv .venv
.\.venv\Scripts\python.exe -m pip install --upgrade pip
.\.venv\Scripts\python.exe -m pip install cmake ninja
.\.venv\Scripts\python.exe -m pip install -e ".[3d,export,dev]"
.\.venv\Scripts\python.exe run_all.py --no-install
.\.venv\Scripts\python.exe -m app.bootstrap
```

La interfaz puede abrir sin Docker. El servicio solo es necesario al iniciar una simulación CFD externa.

## Pruebas

```powershell
.\.venv\Scripts\python.exe -m pytest python/tests -q
ctest --test-dir build/windows-current -C Release --output-on-failure
Push-Location kutta
go test ./...
Pop-Location
```

Línea base de la versión `v1.0.0`:

- 112 pruebas Python de la aplicación;
- 1 ejecutable de pruebas C++;
- pruebas Go en los paquetes Kutta, foil, LBM, scene, sceneio y viz.

## Construir el ejecutable

Después de preparar el entorno, compilar el núcleo y generar Kutta:

```powershell
.\.venv\Scripts\python.exe -m pip install pyinstaller
.\.venv\Scripts\python.exe build_kutta.py
.\.venv\Scripts\python.exe build_exe.py --mode both
```

Los resultados locales son:

- `output/Sultana-del-Norte.exe`: ejecutable único;
- `output/Sultana-del-Norte/Sultana-del-Norte.exe`: carpeta portable.

Los paquetes versionados y sus hashes se generan fuera del historial Git.

## Alcance de validación

Los datos aerodinámicos, propiedades de masa, curvas de empuje y ganancias incluidas son preliminares o de ensayo salvo que su archivo indique lo contrario. Kutta es una herramienta cualitativa para observar patrones de flujo; no sustituye CFD validado ni ensayos físicos.

## Licencia de terceros

Kutta fue desarrollado por Cesar Gimenes y se distribuye bajo licencia MIT. Consulta [`kutta/LICENSE`](kutta/LICENSE) y el archivo raíz [`THIRD_PARTY_NOTICES.md`](../THIRD_PARTY_NOTICES.md).

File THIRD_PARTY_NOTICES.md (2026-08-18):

# Avisos de componentes de terceros

Sultana del Norte incorpora o distribuye junto con su código componentes desarrollados por terceros. Sus licencias se conservan y prevalecen sobre cualquier indicación general del repositorio para esos componentes.

## Kutta — túnel de viento 2D

- Autor: Cesar Gimenes
- Proyecto original: [github.com/crgimenes/kutta](https://github.com/crgimenes/kutta)
- Licencia: MIT
- Ubicación en este repositorio: `04-app-sultana/kutta/`
- Texto de licencia: `LICENSES/Kutta-MIT.txt`

El módulo se integra para visualización cualitativa de flujo. No sustituye un análisis CFD validado ni resultados de túnel de viento físico.

## Dependencias administradas por gestores de paquetes

Las dependencias Python, Go, C++ y Arduino se declaran en sus respectivos archivos de proyecto. Cada paquete conserva la licencia otorgada por su autor. El hecho de aparecer como dependencia no implica autoría de Space NL.

## Código propio

Mientras no exista un archivo `LICENSE` en la raíz, no se concede automáticamente permiso para copiar, modificar o redistribuir el código propio de Sultana del Norte. Esto no limita los derechos concedidos por las licencias de terceros anteriores.

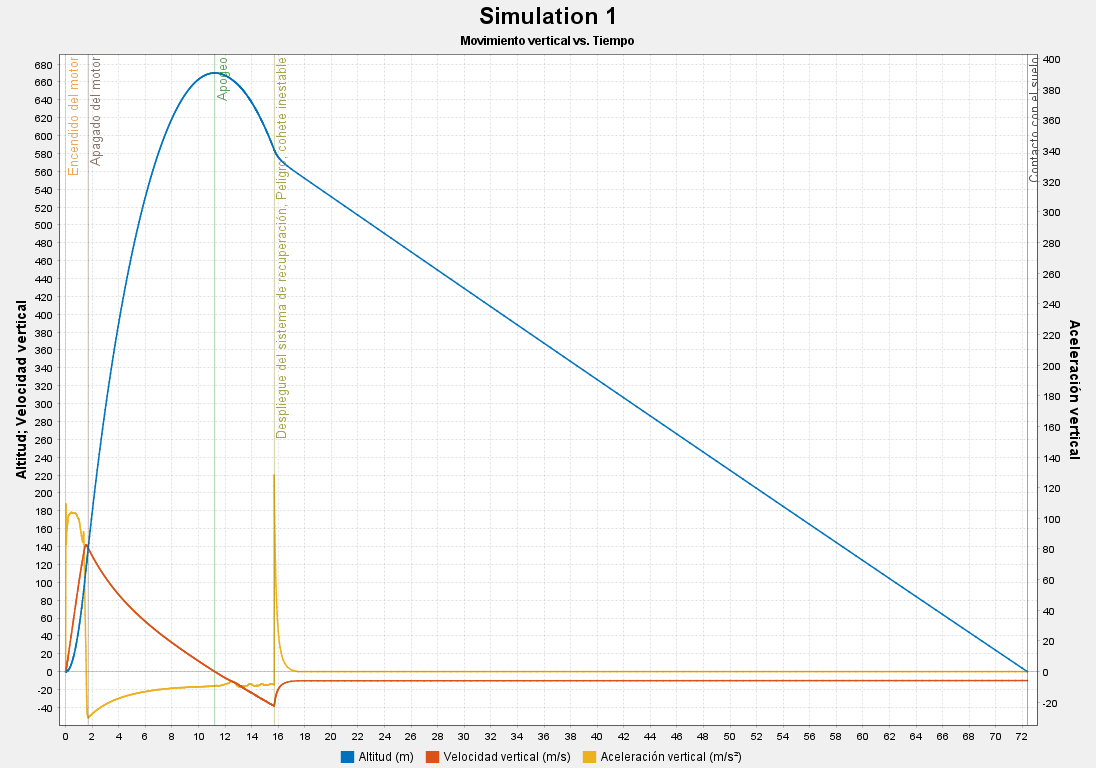
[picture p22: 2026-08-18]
01-diseno-cad/renders/simulacion-openrocket.png

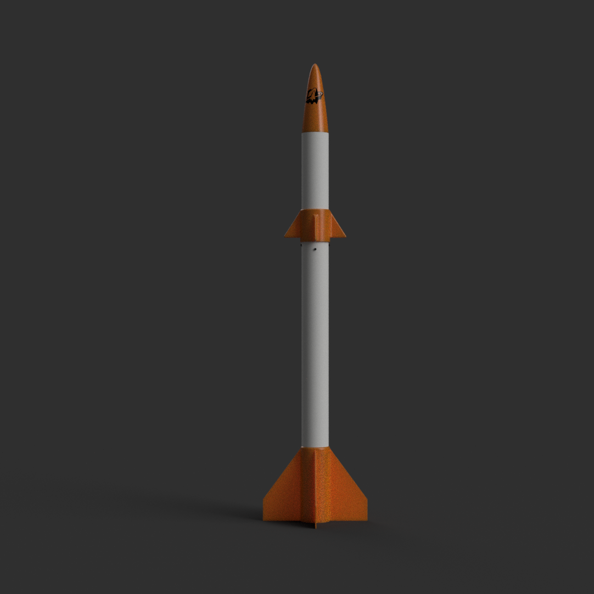
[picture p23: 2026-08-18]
01-diseno-cad/renders/captura-analisis-cad.png

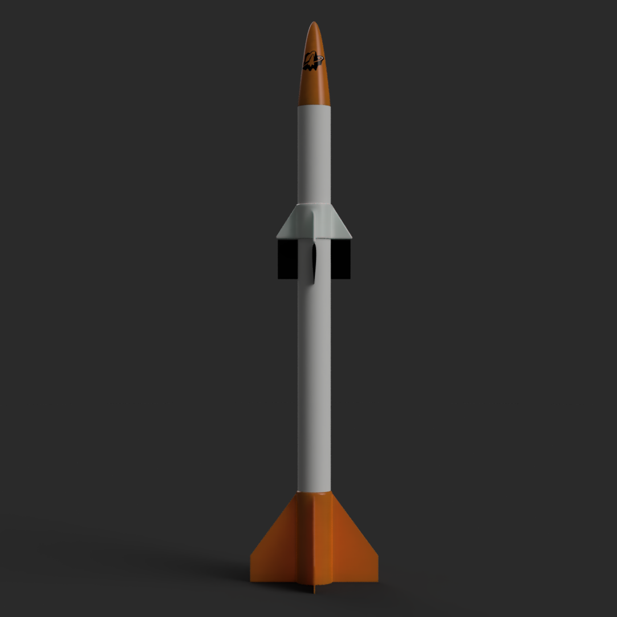
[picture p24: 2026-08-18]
01-diseno-cad/renders/detalle-canards-02.png

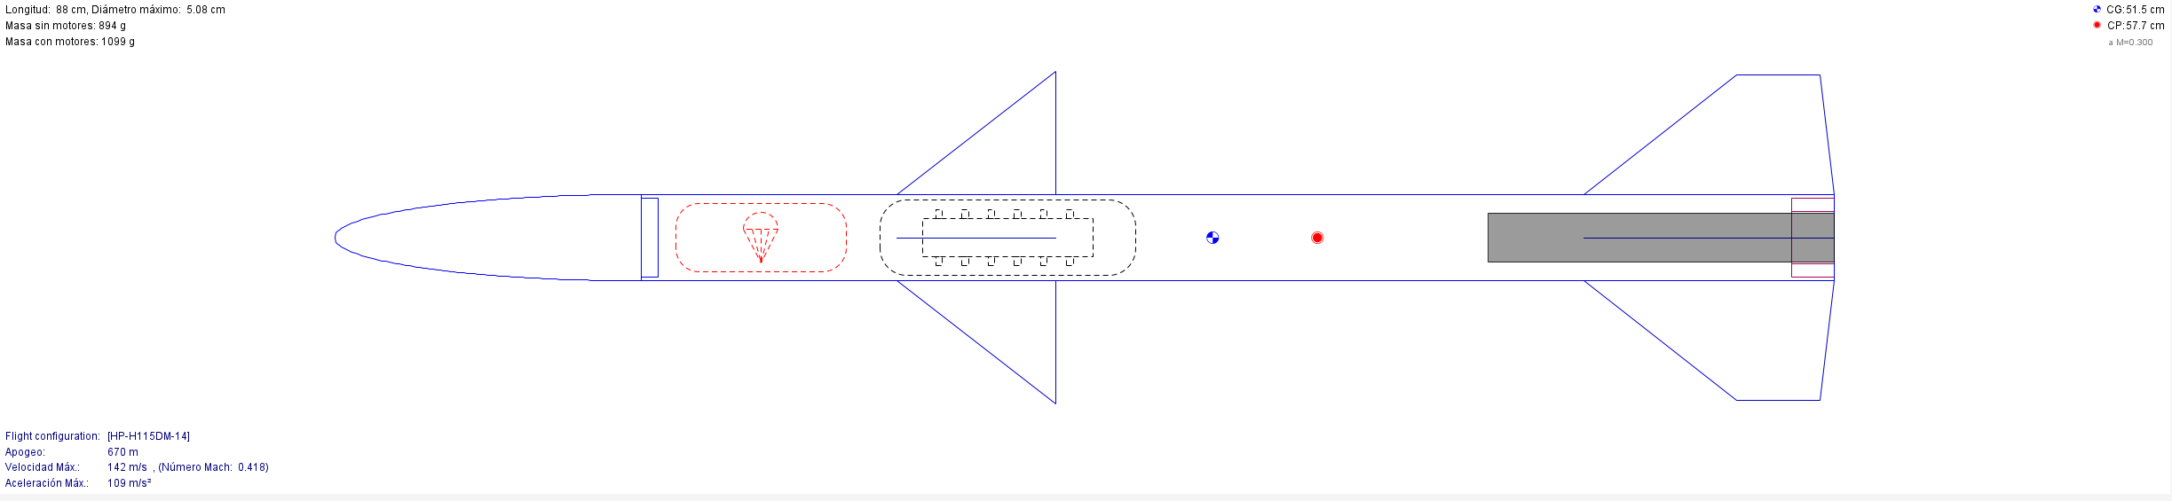
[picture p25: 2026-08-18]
01-diseno-cad/renders/captura-cad-01.png

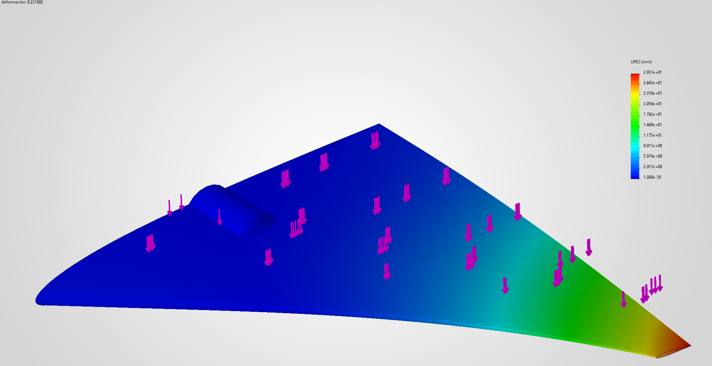
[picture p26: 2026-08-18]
01-diseno-cad/renders/captura-cad-02.png

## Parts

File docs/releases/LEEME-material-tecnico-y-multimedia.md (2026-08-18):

# Material técnico y multimedia · Sultana del Norte

Este paquete reúne la evidencia pesada que se mantiene fuera del historial Git para que el repositorio siga siendo rápido de clonar.

## Contenido

| Carpeta | Contenido | Archivos |
|---|---|---:|
| `multimedia/fotografias/` | Fotografías de cámara y material gráfico | 158 |
| `multimedia/videos/` | Videos breves de evidencia | 4 |
| `cad-interactivo/` | Visualizadores HTML, animaciones MP4 y exportaciones ZIP únicas | 12 |
| `electronica/` | BOM interactiva de la PCB para consulta sin conexión | 1 |
| **Total** | Material técnico y multimedia | **175** |

Las 162 fotografías y videos son contenidos distintos por SHA-256. En los recursos CAD se conservó una sola copia de cada contenido idéntico y se normalizaron los nombres públicos.

## Cómo consultar los archivos

- Abre los archivos `.html` con un navegador moderno.
- Reproduce los `.mp4` con cualquier reproductor compatible con H.264.
- Los `.zip` dentro de `cad-interactivo/` son exportaciones originales asociadas a las animaciones y pueden extraerse por separado.
- `electronica/interactive-bom.html` permite explorar componentes y posiciones de la PCB sin conexión.

Este material sirve como evidencia y referencia de diseño; no es necesario para ejecutar la aplicación de escritorio.

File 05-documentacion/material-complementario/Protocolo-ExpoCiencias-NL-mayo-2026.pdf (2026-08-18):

## ExpoCiencias Nuevo León 2026

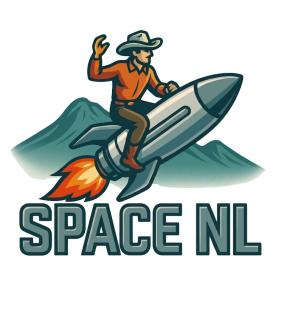
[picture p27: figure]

### Comunidad Space NL

ExpoCNL-S-CE-162

Sistema de Estabilización Activa y cálculo de trayectoria “Sultana del Norte”: Mitigación de Weathercocking en Cohetes Experimentales de Pequeño Calibre mediante Canards con Control PID en Lazo Cerrado

Autores: Aurelio Salas González

Gael Sebastián García Azpeytia

Sergio Axell Flores Obando

Asesor: Fernando Alonso Villalobos

Área: Ciencias Espaciales, CE

Categoría: Superior, S

Monterrey, Nuevo León

Mayo 2026

## RESUMEN

El presente proyecto de investigación e innovación tecnológica documenta el diseño, desarrollo

y validación preliminar del sistema “Sultana del Norte”, una arquitectura de estabilización activa

para cohetes experimentales amateur de 50.8 mm de diámetro. La problemática abordada es la

inestabilidad inducida por viento cruzado, fenómeno conocido como weathercocking, que

ocasiona desviaciones significativas en la trayectoria balística durante el régimen de baja

velocidad inmediatamente posterior al despegue, comprometiendo la seguridad del rango de

operación y la fiabilidad del despliegue del paracaídas. La metodología aplicada es de

investigación experimental con enfoque de ingeniería, comprendiendo: (i) caracterización

aerodinámica mediante el método de Barrowman y modelado del margen de estabilidad

estática; (ii) diseño de una aviónica embebida basada en microcontrolador ESP32-S3, unidad de

medición inercial BNO055 con fusión sensorial por cuaterniones y altímetro barométrico

BMP390; (iii) implementación de un lazo de control PID de actitud a 100 Hz que acciona dos

canards mediante servomotores KST X08 PLUS; (iv) validación mediante un esquema Hardware-

In-the-Loop con simulador dinámico 6-DoF en Python. Como resultados se obtuvieron una

arquitectura electromecánica que cumple las restricciones volumétricas del fuselaje, un firmware

con máquina de estados y rutinas failsafe, y, un mecanismo de transmisión tipo linkage arm que

garantiza repetibilidad angular. Se concluye que el sistema constituye una contribución viable a

la mitigación del weathercocking en plataformas estudiantiles con propelente sólido tipo candy,

aportando al desarrollo de tecnología aeroespacial nacional con costos accesibles.

Palabras clave: Cohete experimental, estabilización activa, canards, control PID, weathercocking,

ESP32-S3, BNO055, Hardware-In-the-Loop, aviónica embebida, propelente candy.

## ABSTRACT

This research and technological innovation project documents the design, development, and

preliminary validation of “Sultana del Norte”, an active stabilization architecture for amateur

experimental rockets with 50.8 mm diameter. The addressed problem is cross-wind induced

instability, known as weathercocking, which produces significant deviations in the ballistic

trajectory during the low-velocity regime immediately after launch, compromising range safety

and the reliability of parachute deployment. The applied methodology is experimental research

with an engineering focus, comprising: (i) aerodynamic characterization through the Barrowman

method and modeling of the static stability margin; (ii) design of embedded avionics based on an

ESP32-S3 microcontroller, a BNO055 inertial measurement unit with quaternion sensor fusion,

and a BMP390 barometric altimeter; (iii) implementation of a 100 Hz PID attitude control loop

that actuates two canards through KST X08 PLUS servomotors; (iv) validation by means of a

Hardware-In-the-Loop scheme with a 6-DoF dynamic simulator in Python. The results obtained

include an electromechanical architecture compliant with the volumetric constraints of the

airframe, firmware with a state machine and failsafe routines, and a linkage arm transmission

mechanism ensuring angular repeatability. It is concluded that the system constitutes a viable

contribution to weathercocking mitigation in student platforms using solid candy propellant,

contributing to national aerospace technology development at accessible costs.

Keywords: Experimental rocket, active stabilization, canards, PID control, weathercocking,

ESP32-S3, BNO055, Hardware-In-the-Loop, embedded avionics, candy propellant.

## LISTA DE ILUSTRACIONES, GRÁFICOS Y TABLAS

ÍNDICE DE TABLAS

Tabla 1. Especificaciones nominales de la plataforma Sultana del Norte | 11
Tabla 2. Características técnicas del servomotor KST X08 PLUS | 16
Tabla 3. Selección de materiales por componente y método de fabricación | 23
Tabla 4. Estructura de la trama de telemetría descendente (32 bytes) | 25
Tabla 5. Componentes del esquema de validación Hardware-In-the-Loop (HIL) | 21
Tabla 6. Cronograma general del desarrollo del proyecto | 19

ÍNDICE DE ILUSTRACIONES

Imagen 1. Representación gráfica del problema | 12
Imagen 2. PCB_V2 de comunicación y control | 24
Imagen 3. Software de adquisición de datos | 25
Imagen 4. Soldadura de la PCB y pruebas eléctricas | 25
Imagen 5. Diseño de soporte para servos | 26
Imagen 6. PCB finalizada y probada | 26

## LISTA DE SIGLAS

A continuación se listan, en orden alfabético, las siglas y acrónimos utilizados a lo largo del

protocolo de investigación, junto con su significado correspondiente.

Sigla | Significado
AGL | Above Ground Level — Altitud sobre el nivel del terreno
APA | American Psychological Association
BLE | Bluetooth Low Energy
CFD | Computational Fluid Dynamics — Dinámica de fluidos computacional
CG | Centro de Gravedad
COCOM | Coordinating Committee for Multilateral Export Controls
CP | Centro de Presión aerodinámico
CPU | Central Processing Unit
DoF | Degrees of Freedom — Grados de libertad
FDM | Fused Deposition Modeling — Modelado por deposición fundida
FPU | Floating Point Unit
FSM | Finite State Machine — Máquina de estados finita
GIS | Geographic Information System
GNC | Guidance, Navigation and Control
GNSS | Global Navigation Satellite System
GPS | Global Positioning System
HDT | Heat Deflection Temperature
HIL | Hardware-In-the-Loop
I²C | Inter-Integrated Circuit (bus serie)
IMU | Inertial Measurement Unit — Unidad de medición inercial
ISM | Industrial, Scientific and Medical (banda de radio)

Sigla | Significado
KNSB | Potassium Nitrate / Sorbitol (propelente candy)
KNDX | Potassium Nitrate / Dextrose (propelente candy)
LDO | Low-Dropout Regulator
LiPo | Lithium Polymer (batería)
MCU | Microcontroller Unit
NAR | National Association of Rocketry
NDOF | Nine Degrees Of Freedom
NVS | Non-Volatile Storage
ODS | Objetivos de Desarrollo Sostenible (Agenda 2030)
OMS | Organización Mundial de la Salud
PID | Proportional-Integral-Derivative (controlador)
PLA | Polylactic Acid (filamento de impresión 3D)
PLA-CF | PLA reforzado con fibra de carbono
PA-CF | Poliamida (Nylon) reforzada con fibra de carbono
PVC | Polyvinyl Chloride — Cloruro de polivinilo
PWM | Pulse Width Modulation
RF | Radiofrecuencia
RSSI | Received Signal Strength Indicator
SDN | Sultana del Norte (clave interna del proyecto)
SM | Static Margin — Margen de estabilidad estática
SoH | State of Health
SPI | Serial Peripheral Interface
UART | Universal Asynchronous Receiver-Transmitter
WGS-84 | World Geodetic System 1984

## ÍNDICE

## 1. INTRODUCCIÓN

La cohetería experimental amateur constituye un campo de aprendizaje multidisciplinario de

creciente relevancia, ya que integra de manera natural conocimientos de aerodinámica,

mecánica estructural, electrónica embebida, teoría de control, ciencias de los materiales y

programación. En el contexto educativo de Nuevo León y de México en general, el desarrollo de

plataformas estudiantiles de bajo costo, utilizando propelentes sólidos tipo candy (mezclas de

nitrato de potasio con sorbitol o dextrosa) y fuselajes de materiales accesibles como el PVC,

permite a los estudiantes adquirir competencias prácticas equivalentes a las de un proyecto

aeroespacial profesional, pero con presupuestos al alcance de una institución educativa o un

equipo estudiantil.

El presente protocolo de investigación documenta el diseño, desarrollo y validación preliminar

del sistema “Sultana del Norte”, una arquitectura de estabilización activa concebida para resolver

una problemática recurrente en cohetes amateur de pequeño calibre: la desviación de

trayectoria inducida por viento cruzado durante los primeros segundos de vuelo, fenómeno

técnicamente denominado weathercocking o veleteo aerodinámico. La solución propuesta

consiste en un par de canards activos —pequeñas aletas frontales móviles— accionados por

servomotores y gobernados por un computador de vuelo dedicado que ejecuta un lazo de control

proporcional-integral-derivativo (PID) en lazo cerrado, tomando como referencia la actitud

absoluta del cohete reportada por una unidad de medición inercial de fusión sensorial.

El proyecto se estructura como un trabajo de ingeniería aplicada que aborda el problema en sus

cinco dimensiones técnicas fundamentales: (i) caracterización del fenómeno físico y

planteamiento aerodinámico; (ii) selección y justificación de la arquitectura electrónica

embebida; (iii) desarrollo matemático del lazo de control; (iv) implementación del firmware con

sus rutinas de seguridad de vuelo; y (v) propuesta mecánica adaptada a las restricciones

volumétricas extremas del fuselaje de dos pulgadas. El alcance documental incluye además la

metodología de validación previa al vuelo mediante Hardware-In-the-Loop (HIL) y la arquitectura

de telemetría con estación de tierra para monitoreo en tiempo real.

La investigación se enmarca en un nivel educativo de bachillerato/preuniversitario, con un

enfoque pedagógico que prioriza la transferencia de conocimiento aeroespacial accesible. La

metodología es de tipo investigación experimental con componente de desarrollo de ingeniería,

sustentada en el marco teórico clásico de Barrowman para aerodinámica de cohetes, en la teoría de control de Åström y Murray para el diseño del PID, y en las hojas técnicas oficiales (datasheets)

de los componentes electrónicos seleccionados. El producto final esperado es un prototipo

funcional capaz de demostrar, primero en banco mediante simulación HIL y posteriormente en

vuelo, una reducción cuantificable de la desviación angular respecto a la vertical en condiciones

de viento cruzado superiores a 10 km/h, contribuyendo así a una mayor seguridad operativa del

rango | de | lanzamiento.

### 1.1. Justificación del Proyecto

La justificación del presente proyecto se sustenta en tres ejes principales: técnico, formativo y de

seguridad operacional. Desde la perspectiva técnica, los cohetes experimentales amateur de

pequeño calibre presentan una vulnerabilidad estructural inherente al fenómeno de

weathercocking: durante el régimen de baja velocidad inmediatamente posterior al despegue

(los primeros 1 a 3 segundos de vuelo), las aletas estabilizadoras pasivas son aerodinámicamente

ineficientes y no pueden corregir las perturbaciones angulares inducidas por componentes

laterales de viento. Esta limitación, ampliamente documentada por la NASA en sus guías de

aerodinámica y por organizaciones de cohetería como la National Association of Rocketry (NAR),

produce desviaciones de trayectoria que pueden exceder el área de seguridad declarada para el

rango de operación, con riesgos para personas y propiedad.

Desde la perspectiva formativa, el desarrollo de un sistema de control activo de vuelo constituye

una oportunidad educativa de altísimo valor para estudiantes de bachillerato y licenciatura en

disciplinas STEM. La integración de electrónica embebida (ESP32-S3, sensores I²C/SPI,

servomotores), matemáticas avanzadas (cuaterniones, ecuaciones diferenciales, transformada

de Tustin), programación en C++ con sistemas en tiempo real, y manufactura aditiva (impresión

3D en PLA/PLA-CF) ofrece un escenario integrador difícilmente replicable en otras temáticas. Esta experiencia es directamente transferible a vocaciones profesionales en ingeniería aeroespacial,

mecatrónica, sistemas de control y desarrollo de tecnología nacional, áreas estratégicas para el

desarrollo económico de Nuevo León y de México.

Desde la perspectiva de seguridad operacional, el sistema propuesto contribuye a elevar el

estándar de seguridad de los lanzamientos estudiantiles. La incorporación de redundancia en el

sistema de recuperación (detección de apogeo con votación 2 de 2 entre criterio barométrico e

inercial), el lockout pirotécnico hasta confirmar liftoff, las rutinas failsafe documentadas y la

telemetría en tiempo real son prácticas que, aunque comunes en aeronáutica profesional, rara

vez se implementan en proyectos amateur. El presente protocolo busca normalizar estas

prácticas en el ecosistema estudiantil mexicano de cohetería.

Existen referencias internacionales relevantes que evidencian la importancia y viabilidad de este

tipo de desarrollos, entre las cuales destacan los proyectos académicos de la Delft Aerospace

Rocket Engineering (DARE) de la Universidad Tecnológica de Delft, específicamente su cohete

“Aether” con estabilización activa supersónica, los proyectos abiertos publicados en plataformas

como GitHub (RocketPy, TritonFC, ActiveControls de la Universidad de Stanford) y los reportes

de cohetería educativa universitaria como el proyecto Capstone de la Northern Arizona

University. La presente propuesta hereda lecciones de estos referentes y las adapta al contexto

de propelente candy y fuselaje PVC, una combinación poco documentada en la literatura técnica.

### 1.2. Planteamiento del Problema

Cuando un cohete experimental amateur abandona la rampa de lanzamiento, su velocidad axial

inicial es típicamente baja (10–20 m/s), lo que implica una presión dinámica reducida y, por

consiguiente, una eficiencia aerodinámica deteriorada de las aletas estabilizadoras pasivas. Si

simultáneamente existe una componente de viento lateral superior a 10 km/h, el centro de

presión —ubicado por diseño aguas abajo del centro de gravedad para garantizar estabilidad

pasiva— actúa como un punto de pivote alrededor del cual el cohete tiende a girar hasta alinear

su eje longitudinal con el vector de velocidad relativa al aire. Este fenómeno, denominado weathercocking, produce un giro hacia el viento de magnitud proporcional al ángulo entre la

trayectoria nominal y dicho vector relativo.

Las consecuencias operativas del weathercocking son tres y revisten gravedad creciente: en

primer lugar, la trayectoria balística se desvía respecto a la vertical, con el riesgo de que el cohete

aterrice fuera del área de seguridad delimitada; en segundo lugar, la reducción del ángulo de

elevación efectivo disminuye el apogeo nominal y, por tanto, comprime la ventana temporal

disponible para el despliegue confiable del paracaídas; en tercer lugar, las sobrecargas

asimétricas sobre las aletas estabilizadoras inducen esfuerzos cortantes que, en materiales como

el PLA empleado típicamente en cohetería estudiantil, pueden producir falla estructural por

delaminación o cizallamiento, especialmente cuando la temperatura del componente excede los

55 °C.

La pregunta de investigación que orienta el presente proyecto se formula del siguiente modo:

¿Es posible diseñar y validar, dentro de las restricciones volumétricas (diámetro interno de 49

mm), energéticas (batería LiPo 2S) y económicas (presupuesto estudiantil) de un cohete

experimental amateur de 2 in de diámetro, una arquitectura de aviónica embebida con canards

activos y control PID que mitigue cuantificablemente la desviación angular inducida por viento

cruzado durante la fase de boost inicial?

La respuesta a esta pregunta debe obtenerse mediante una metodología de ingeniería rigurosa

que integre análisis aerodinámico, diseño electrónico, modelado matemático, implementación

de software embebido en tiempo real, validación HIL y, eventualmente, ensayos de vuelo

controlados.

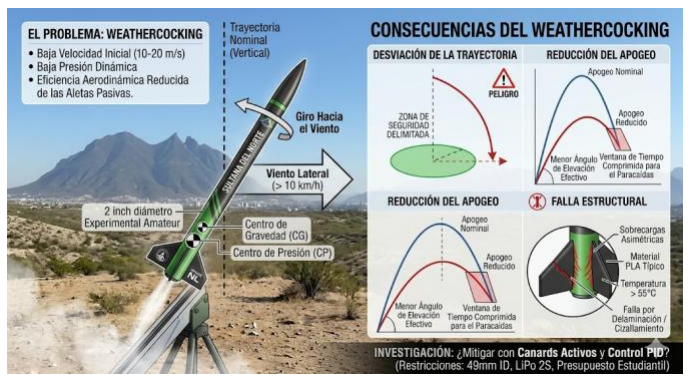
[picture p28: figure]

Imagen 1. Representación gráfica del problema

### 1.3. Meta de Ingeniería

Dado que el presente proyecto se enmarca en un trabajo de desarrollo tecnológico aplicado más

que en una investigación científica pura, se opta por formular una meta de ingeniería en lugar de

una hipótesis estadística clásica. La meta se establece de la siguiente manera:

Diseñar, integrar y validar mediante simulación Hardware-In-the-Loop un sistema de

estabilización activa basado en canards con control PID que, operando dentro del fuselaje

estándar de 2 in del cohete Sultana del Norte, sea capaz de reducir en al menos un 50 % la

desviación angular máxima respecto a la vertical en presencia de un perfil de viento cruzado de

hasta 25 km/h, manteniendo en todo momento la integridad estructural del vehículo y la

estabilidad pasiva del mismo en caso de falla del sistema activo.

Esta meta se considera alcanzada si, al término del proyecto, se demuestra mediante la campaña

HIL: (i) que el lazo de control PID opera de forma estable a 100 Hz en el hardware seleccionado;

(ii) que las rutinas failsafe responden correctamente ante los escenarios de falla simulados; (iii)

que la deflexión máxima de los canards no excede los ±15° y se mantiene dentro de los rangos

de torque y velocidad nominales del servomotor; y (iv) que la dinámica simulada del vehículo,

alimentada por curvas reales de empuje del propelente candy, exhibe la reducción angular

comprometida frente a perfiles de viento estocásticos tipo Dryden o von Kármán.

### 1.4. Objetivos

### 1.4.1. Objetivo General

Diseñar, integrar y validar preliminarmente un sistema de estabilización activa basado en canards

con control PID en lazo cerrado para el cohete experimental Sultana del Norte, capaz de mitigar

la desviación angular inducida por viento cruzado durante la fase de boost inicial, dentro de las

restricciones volumétricas, energéticas y económicas propias de una plataforma estudiantil con

propelente candy.

### 1.4.2. Objetivos Particulares

- Caracterizar el fenómeno aerodinámico de weathercocking en cohetes amateur de

pequeño calibre mediante el método de Barrowman y el modelo de margen de

estabilidad estática, identificando los parámetros críticos que determinan la severidad del

fenómeno.

- Diseñar la arquitectura electrónica embebida de la aviónica, seleccionando y justificando

técnicamente cada componente (microcontrolador, IMU, altímetro, GNSS, servos, drivers

PWM y módulos de telemetría RF) en función de los requerimientos del lazo de control y

de las restricciones volumétricas del fuselaje.

- Desarrollar el modelo matemático del lazo de control PID de actitud, incluyendo su

discretización para implementación embebida a 100 Hz, así como la formulación de la ley

de mezcla a dos canards y los criterios de saturación, anti-windup y filtrado del término

derivativo.

- Implementar el firmware de vuelo en el microcontrolador ESP32-S3 bajo el paradigma de

máquina de estados finita, integrando rutinas de calibración en rampa, bucle de control

en tiempo real, detección redundante de apogeo, logging local y modos failsafe

documentados.

- Diseñar el subsistema mecánico de transmisión tipo linkage arm con rodamientos

miniatura, así como la selección de materiales y métodos de fabricación (impresión 3D en

PLA-CF y PA-CF, mecanizado de aluminio 6061-T6, eje de acero AISI 304) compatible con

las restricciones internas del fuselaje de 2 in.

- Validar la integración funcional del sistema mediante un esquema Hardware-In-the-Loop

con simulador dinámico 6-DoF en Python, alimentado por curvas reales de empuje del

propelente candy y modelos estocásticos de viento, y caracterizar la respuesta del lazo

cerrado en escenarios nominales y de falla.

- Diseñar la arquitectura de telemetría descendente (NRF24L01+ PA/LNA) y la estación de

tierra (dashboard 3D, gráficas temporales, mapa GIS y panel de comandos), incluyendo el

protocolo de tramas binarias de 32 bytes con CRC-16 para monitoreo en tiempo real

durante el vuelo.

## 2. MARCO TEÓRICO

El marco teórico del presente proyecto integra conocimientos provenientes de cinco disciplinas

técnicas que sustentan tanto la formulación del problema como la solución propuesta:

aerodinámica de cohetes, teoría de control en lazo cerrado, fusión sensorial inercial mediante

cuaterniones, electrónica embebida de tiempo real y ciencia de materiales aplicada a

manufactura aditiva. Las siguientes subsecciones desarrollan cada uno de estos componentes

conceptuales con el grado de detalle necesario para fundamentar el diseño descrito en los

capítulos posteriores.

### 2.1. Fenómeno de Weathercocking

El término weathercocking, traducido al español como veleteo o cabeceo aerodinámico, describe

el comportamiento por el cual un cohete tiende a girar hacia el viento durante el inicio de su

trayectoria. La explicación física es directa: cuando el cohete tiene baja velocidad axial, el vector

de velocidad relativa al aire resulta de la suma vectorial de la velocidad propia y la velocidad del

viento. Si esta última es comparable o mayor que la primera, el ángulo de ataque efectivo del

cohete respecto al viento es significativo. El centro de presión aerodinámico, ubicado por diseño

aguas abajo del centro de gravedad para garantizar estabilidad pasiva, genera un momento

restitutivo que orienta el eje del vehículo hacia el viento.

De acuerdo con la Beginner’s Guide to Aeronautics de la NASA, este fenómeno se intensifica con

cohetes que tienen un margen de estabilidad estática elevado y con tiempos prolongados de baja

velocidad, condición que se presenta de manera crítica en plataformas con propelente de

impulso reducido como el candy. La mitigación clásica del weathercocking se realiza con rampas

de lanzamiento más largas (que permiten al cohete adquirir mayor velocidad antes de quedar

bajo influencia plena del viento) y con limitación operativa: simplemente no lanzar cuando el

viento excede umbrales seguros. La incorporación de control activo representa una tercera línea

de defensa que amplía la ventana operativa del sistema.

### 2.2. Aerodinámica de Aletas y Método de Barrowman

El cálculo del centro de presión aerodinámico y de los coeficientes de sustentación de un cohete

con aletas se realiza tradicionalmente mediante el método propuesto por James S. Barrowman

en su tesis de maestría de 1967 en la Catholic University of America. Este método, hoy estándar

en el ámbito amateur y semi-profesional, descompone el cohete en módulos geométricos

elementales (ojiva, transiciones cónicas, cuerpo cilíndrico, aletas) y calcula la contribución de

cada uno al centro de presión total mediante una suma ponderada por el coeficiente de fuerza

normal.

Para una aleta deflectada a un ángulo pequeño α respecto a la corriente libre (régimen lineal, α

< 10°), la fuerza de sustentación L generada se modela mediante la ecuación clásica:

L = q · S · C_L(α) = ½ · ρ · V² · S · C_L(α) (Ec. 2.1)

Donde q es la presión dinámica, ρ la densidad atmosférica local, V la velocidad relativa, S el área

plana de la superficie y C_L(α) el coeficiente de sustentación. Para ángulos pequeños se aproxima

linealmente C_L(α) ≈ C_Lα · α, donde C_Lα es la pendiente de sustentación, típicamente

comprendida entre 2π y 2π/√(1 − M²) por radián según la teoría de Prandtl-Glauert para perfiles

delgados en flujo subsónico compresible.

### 2.3. Margen de Estabilidad Estática

El margen de estabilidad estática SM se define como la distancia adimensional, expresada en

calibres de diámetro, entre el centro de presión aerodinámico y el centro de gravedad del

vehículo:

SM = ( x_cp − x_cg ) / D (Ec. 2.2)

La regla empírica consolidada en cohetería amateur establece que un SM comprendido entre 1.0

y 2.0 calibres corresponde al régimen estable: por debajo de 1.0, el cohete tiende a inestabilidad

pasiva y puede entrar en tumbling; por encima de 2.0, el cohete se vuelve sobre-estable y

excesivamente sensible al weathercocking, agravando precisamente la problemática que el

presente proyecto busca resolver. La introducción de canards activos transforma el centro de

presión efectivo de una constante geométrica en una función dinámica del ángulo de deflexión

comandado, otorgando al sistema la capacidad de modular su estabilidad en tiempo real.

### 2.4. Controlador PID

El controlador proporcional-integral-derivativo (PID), formulado en su forma moderna por Nicholas Minorsky en 1922 y consolidado por la obra de Karl Johan Åström y Richard Murray, es

la estrategia de control más ampliamente desplegada en aplicaciones de ingeniería de procesos

y mecatrónica. Su forma continua canónica es:

u(t) = K_p · e(t) + K_i · ∫₀ᵗ e(τ) dτ + K_d · de(t)/dt (Ec. 2.3)

Donde u(t) es la señal de control aplicada al actuador (deflexión angular del canard en este caso),

e(t) = θ_ref − θ(t) es el error entre la referencia y la variable medida, y K_p, K_i, K_d son las

ganancias proporcional, integral y derivativa respectivamente. El término proporcional genera

una respuesta inmediata proporcional al error; el integral elimina el error estacionario en

presencia de perturbaciones constantes; y el derivativo aporta amortiguamiento al anticipar la

tendencia del error. La discretización para implementación embebida a paso fijo se realiza

mediante aproximación de Tustin para el integral y diferencias hacia atrás para el derivativo.

### 2.5. Cuaterniones y Fusión Sensorial Inercial

La representación de la orientación de un cuerpo rígido en el espacio tridimensional puede

realizarse mediante diversos esquemas matemáticos, siendo los más comunes los ángulos de

Euler (roll-pitch-yaw), la matriz de cosenos directores y los cuaterniones unitarios. Los ángulos

de Euler, aunque intuitivos, sufren de la singularidad conocida como gimbal lock cuando uno de

los ángulos se aproxima a ±90°, condición que puede presentarse en un cohete durante

maniobras de cabeceo pronunciado o trayectorias verticales puras.

Los cuaterniones unitarios q = (qw, qx, qy, qz), introducidos por William Rowan Hamilton en 1843,

representan rotaciones tridimensionales sin singularidades y con eficiencia computacional

superior a las matrices 3x3. La unidad de medición inercial BNO055 de Bosch Sensortec integra

un microcontrolador ARM Cortex-M0 dedicado que ejecuta un algoritmo de fusión sensorial

propietario combinando datos del acelerómetro, giroscopio y magnetómetro de tres ejes, y

entrega directamente cuaterniones unitarios a una tasa de 100 Hz. Esta arquitectura libera al procesador principal del cohete (ESP32-S3) de la carga computacional asociada a un filtro de

Kalman extendido o a una implementación propia del algoritmo de Madgwick.

### 2.6. Propulsión Sólida Tipo Candy (KNSB / KNDX)

Los propelentes sólidos tipo candy, popularizados en la comunidad amateur por el ingeniero

canadiense Richard Nakka, son mezclas de un oxidante inorgánico (típicamente nitrato de

potasio, KNO₃) con un combustible orgánico de origen alimentario (sorbitol C₆H₁₄O₆, dextrosa

C₆H₁₂O₆ o sacarosa). Las denominaciones técnicas KNSB y KNDX corresponden a las

combinaciones potasio-sorbitol y potasio-dextrosa respectivamente, con proporciones másicas

oxidante/combustible cercanas a 65/35.

Estos propelentes ofrecen un impulso específico Isp del orden de 130–145 segundos, valor

modesto frente a propelentes profesionales pero suficiente para apogeos de varios cientos de

metros con vehículos de pequeño calibre. Su principal ventaja es la accesibilidad de los reactivos

y la posibilidad de manufactura segura en condiciones de laboratorio estudiantil con

procedimientos térmicos controlados. Su principal limitación es la variabilidad lote-a-lote en la

curva de empuje F(t), del orden del 5–15 %, factor que debe asumirse explícitamente en el diseño

del sistema de control: la autoridad de los canards depende cuadráticamente de la velocidad, y

la velocidad depende a su vez del empuje real entregado por el motor.

### 2.7. Microcontroladores ESP32 y Buses Serie Estándar

El microcontrolador ESP32-S3 de Espressif Systems pertenece a la familia de SoC (System on Chip)

basada en núcleo Xtensa LX7 dual-core operando a 240 MHz, con unidad de punto flotante (FPU)

en hardware, 512 kB de SRAM interna, soporte para PSRAM externa y conectividad Wi-Fi 802.11

b/g/n y Bluetooth Low Energy 5.0 integradas. Para aplicaciones de control embebido en tiempo

real, el ESP32-S3 ofrece múltiples canales independientes de los buses serie estándar I²C (Inter-

Integrated Circuit), SPI (Serial Peripheral Interface) y UART (Universal Asynchronous Receiver-

Transmitter), lo que permite asignar cada periférico a su propio bus y evitar colisiones de tráfico

durante el bucle de control.

El bus I²C, definido por la especificación de NXP Semiconductors, opera a velocidades de 100 kHz

(standard), 400 kHz (fast) o 1 MHz (fast plus), con direccionamiento de 7 bits y arbitraje multi-

maestro nativo. El SPI ofrece velocidades superiores (decenas de MHz) en modo full-duplex con

líneas dedicadas de chip-select por dispositivo. La selección de I²C para el BNO055, el BMP390 y

el PCA9685, junto con SPI para el módulo de radio NRF24L01+ y UART para el GPS NEO-M8N,

constituye una topología de cableado mínimo dentro del volumen interno crítico del fuselaje.

## 3. PROCESO METODOLÓGICO DEL DESARROLLO DEL

## PROYECTO

El presente proyecto se desarrolla bajo una metodología de investigación experimental con

componente de desarrollo de ingeniería, siguiendo el paradigma clásico de diseño iterativo de

sistemas embebidos: análisis del problema, requerimientos, diseño conceptual, diseño detallado,

implementación, validación y refinamiento. Esta metodología es estándar en proyectos

aeroespaciales y permite gestionar la complejidad multidisciplinaria intrínseca del sistema. A

continuación se detallan la metodología, el tipo de investigación, el cronograma, los recursos y

los procedimientos seguidos.
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

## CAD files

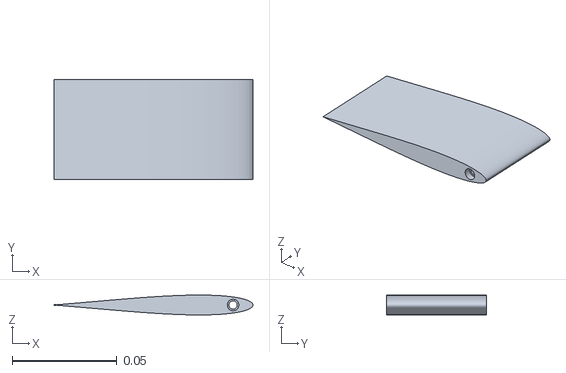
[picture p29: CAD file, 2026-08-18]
04-app-sultana/data/models/ensamble_todo_v2_cfd_5.obj
0.0951 x 0.0475 x 0.00951

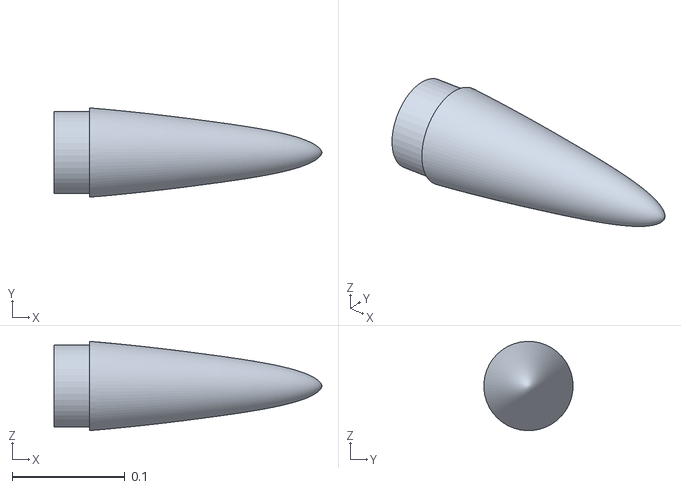
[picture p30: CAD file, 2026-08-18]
04-app-sultana/data/models/ensamble_todo_v2_cfd_normal_1.obj
0.238 x 0.0791 x 0.0792

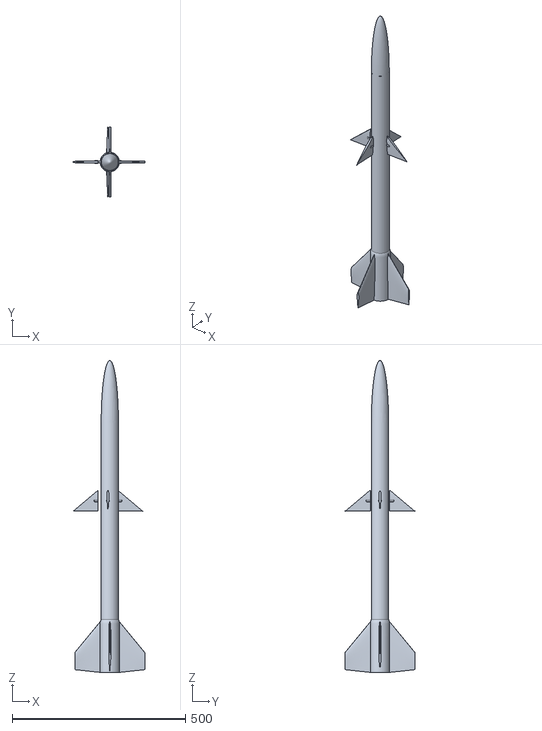
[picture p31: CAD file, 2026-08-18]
04-app-sultana/data/models/ensamble_naca_661_212.stl
207.0 x 202.4 x 901.7

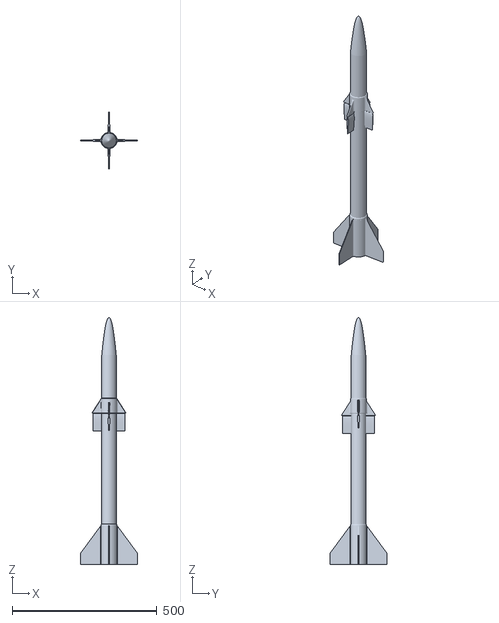
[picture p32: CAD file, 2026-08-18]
04-app-sultana/data/models/ensamble_todo_v2.stl
194.9 x 194.9 x 852.0

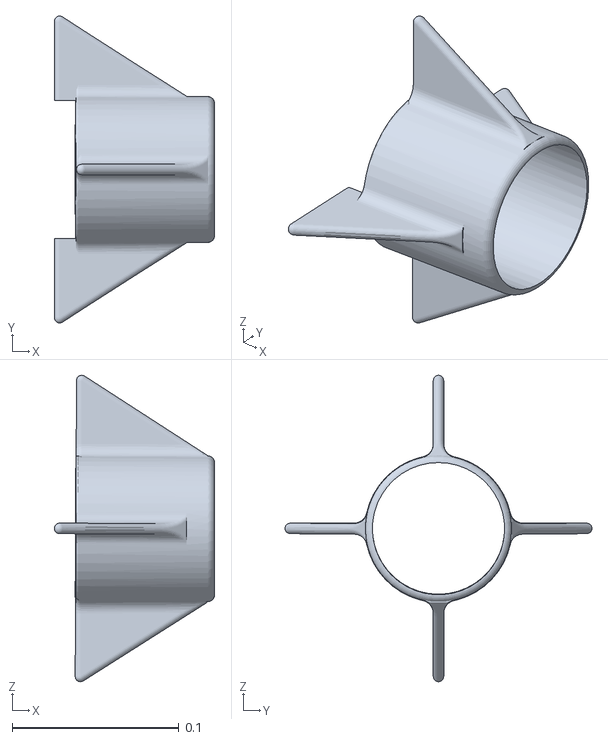
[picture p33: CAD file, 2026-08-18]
04-app-sultana/data/models/ensamble_todo_v2_cfd_2.obj
0.0962 x 0.184 x 0.184

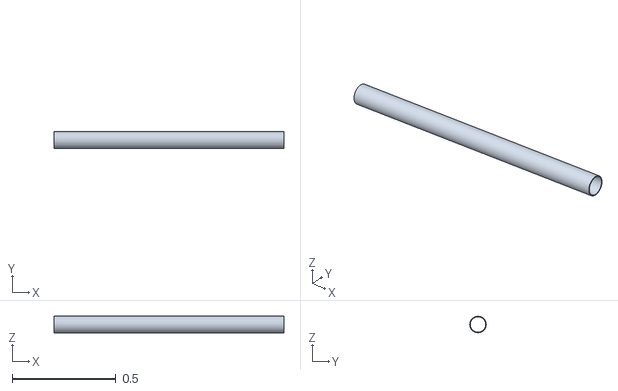
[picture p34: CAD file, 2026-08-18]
04-app-sultana/data/models/ensamble_todo_v2_cfd_0.obj
1.11 x 0.0798 x 0.0798

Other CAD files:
04-app-sultana/data/models/ensamble_todo_v2_cfd_normal_4.obj
04-app-sultana/data/models/ensamble_todo_v2_cfd_normal_7.obj
04-app-sultana/data/models/ensamble_todo_v2_cfd_7.obj
04-app-sultana/data/models/ensamble_todo_v2_cfd_4.obj
04-app-sultana/data/models/ensamble_todo_v2_cfd_6.obj
04-app-sultana/data/models/ensamble_todo_v2_cfd_normal_2.obj
04-app-sultana/data/models/ensamble_todo_v2_cfd_normal_6.obj
04-app-sultana/data/models/ensamble_todo_v2_cfd_normal_5.obj
04-app-sultana/data/models/ensamble_todo_v2_cfd_normal_0.obj
04-app-sultana/data/models/ensamble_todo_v2_cfd_1.obj

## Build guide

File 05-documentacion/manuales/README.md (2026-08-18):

# Manuales

Los manuales mantenidos junto al código son la referencia operativa vigente:

- [Aplicación de escritorio](../../04-app-sultana/README.md)
- [Firmware ESP32-S3](../../03-firmware-esp32/README.md)
- [Electrónica y aviónica](../../02-electronica/README.md)
- [Diseño CAD y CFD](../../01-diseno-cad/README.md)

Esta decisión evita duplicar instrucciones que podrían quedar desactualizadas frente al código. El reporte técnico integral permanece en [`../informe-tecnico/`](../informe-tecnico/).

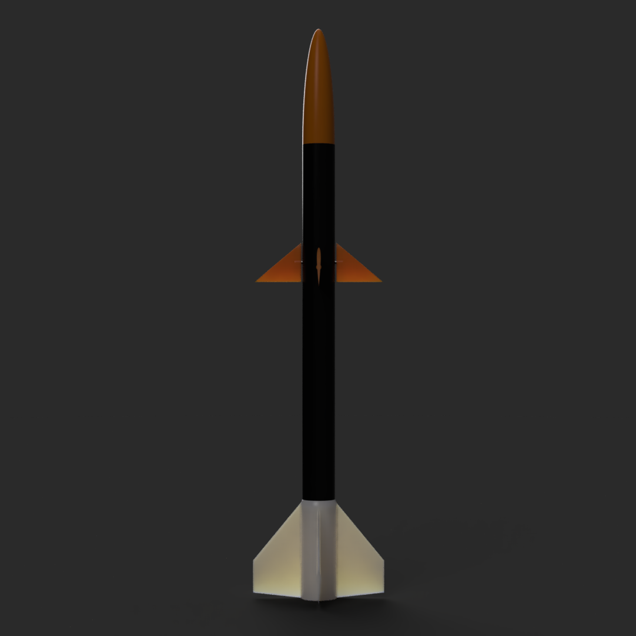
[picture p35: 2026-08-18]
01-diseno-cad/renders/ensamble-validacion-vista-01.png

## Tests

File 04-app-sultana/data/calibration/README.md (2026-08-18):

# Calibration evidence

Store versioned evidence here: motor static-fire reductions, mass/CG/inertia reports, and aerodynamic characterization. The UI only enables `flight_prediction` when the corresponding three booleans in the vehicle configuration are `true`; changing those flags must be reviewed with the accompanying evidence.

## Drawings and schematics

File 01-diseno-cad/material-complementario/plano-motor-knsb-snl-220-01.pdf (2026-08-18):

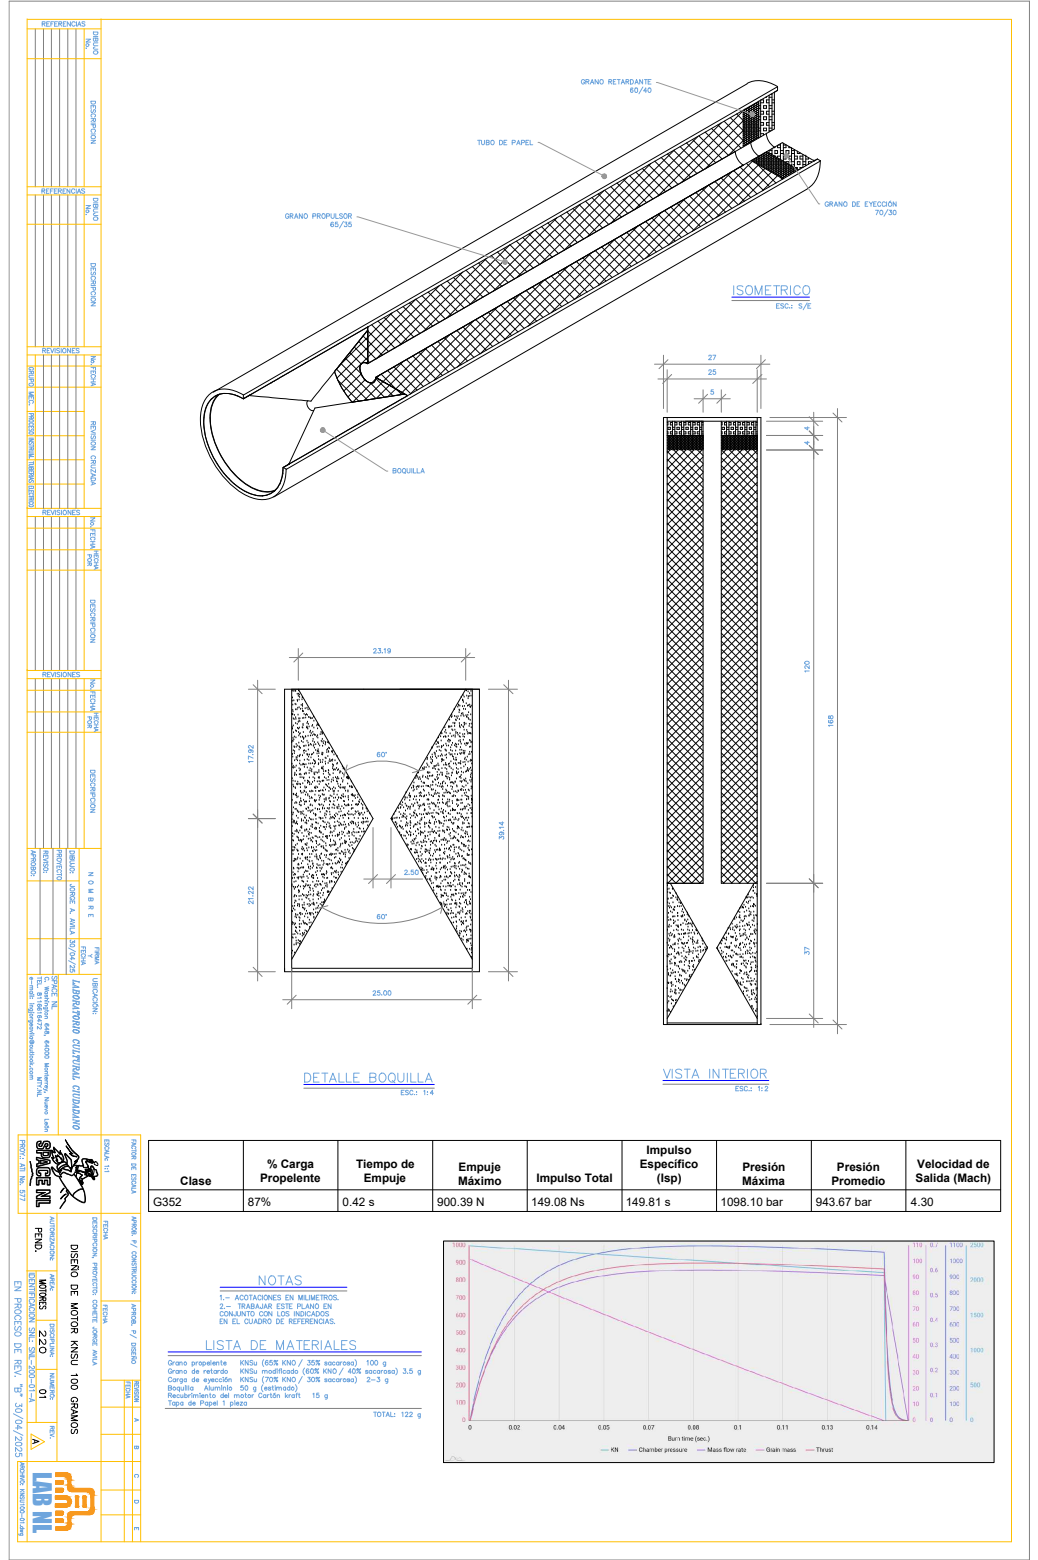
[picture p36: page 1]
(Isp); Presión Máxima; Presión Promedio; Velocidad de Salida (Mach) G352; 1098.10 bar; 943.67 bar

LAB NL Clase % Carga Propelente Tiempo de Empuje Empuje Máximo Impulso Total

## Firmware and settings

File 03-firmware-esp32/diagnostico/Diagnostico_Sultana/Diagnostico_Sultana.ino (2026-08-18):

/*
  DIAGNOSTICO COMPLETO SULTANA DEL NORTE - ESP32-S3
  Abrir directamente con Arduino IDE.

  Placa: ESP32S3 Dev Module
  Monitor serie: 115200 baud, "Nueva linea"

  IMPORTANTE: la primera prueba de servos se realiza SIN varillajes/canards.
*/

#include <Wire.h>
#include <SPI.h>
#include <SD.h>
#include <Adafruit_BNO08x.h>
#include <Adafruit_BMP3XX.h>
#include <ESP32Servo.h>
#include <RF24.h>
#include <TinyGPS++.h>

// ----------------------- PINES DEL ESQUEMA -----------------------
const int PIN_BNO_RST = 4;
const int PIN_BNO_INT = 5;
const int PIN_SD_CS = 6;
const int PIN_NRF_IRQ = 7;
const int PIN_I2C_SCL = 9;
const int PIN_NRF_CSN = 10;
const int PIN_SPI_MOSI = 11;
const int PIN_SPI_MISO = 12;
const int PIN_SPI_SCK = 13;
const int PIN_NRF_CE = 14;
const int PIN_GPS_PPS = 15;
const int PIN_GPS_RX = 16;  // RX ESP32 <- TX GPS
const int PIN_GPS_TX = 17;  // TX ESP32 -> RX GPS
const int PIN_I2C_SDA = 18;
const int PIN_SERVO[4] = {41, 2, 21, 47};

// KST X08 Plus V6.0
const int SERVO_HZ = 333;
const int SERVO_MIN_US = 900;
const int SERVO_MAX_US = 2100;
int servoCentroUs[4] = {1500, 1500, 1500, 1500};
int servoDireccion[4] = {+1, +1, +1, +1};
const float US_POR_GRADO = 1000.0f / 120.0f;
const float PRESION_NIVEL_MAR_HPA = 1013.25f;  // Ajustar con estacion local.

const byte RADIO_DIRECCION[6] = "SNL01";
const byte RADIO_CANAL = 76;  // 2476 MHz

Adafruit_BNO08x bno(PIN_BNO_RST);
Adafruit_BMP3XX bmp;
sh2_SensorValue_t eventoBno;
TinyGPSPlus gps;
HardwareSerial gpsSerial(1);
RF24 radio(PIN_NRF_CE, PIN_NRF_CSN);
Servo servos[4];

bool bnoOK = false;
bool bmpOK = false;
bool sdOK = false;
bool radioOK = false;
bool servosArmados = false;
bool transmitirDatos = true;

float qw = 1.0f, qx = 0.0f, qy = 0.0f, qz = 0.0f;
float gx = 0.0f, gy = 0.0f, gz = 0.0f;
float ax = 0.0f, ay = 0.0f, az = 0.0f;
float presionPa = NAN;
float temperaturaC = NAN;
float altitudBmpM = NAN;
uint32_t ultimaImpresionMs = 0;
volatile uint32_t pulsosPPS = 0;

void IRAM_ATTR interrupcionPPS() {
  pulsosPPS++;
}

bool activarReportesBNO() {
  bool ok = true;
  ok &= bno.enableReport(SH2_GAME_ROTATION_VECTOR, 10000);   // 100 Hz
  ok &= bno.enableReport(SH2_GYROSCOPE_CALIBRATED, 10000);  // 100 Hz
  ok &= bno.enableReport(SH2_LINEAR_ACCELERATION, 10000);   // 100 Hz
  return ok;
}

void escanearI2C() {
  Serial.println("\n--- ESCANEO I2C ---");
  int encontrados = 0;
  for (byte direccion = 1; direccion < 127; direccion++) {
    Wire.beginTransmission(direccion);
    if (Wire.endTransmission() == 0) {
      Serial.printf("Dispositivo encontrado: 0x%02X\n", direccion);
      encontrados++;
    }
  }
  Serial.printf("Total: %d. Esperados: BNO085=0x4A y BMP390=0x76 o 0x77\n\n",
                encontrados);
}

void leerBNO() {
  if (!bnoOK) return;
  if (bno.wasReset()) bnoOK = activarReportesBNO();

  for (int i = 0; i < 16 && bno.getSensorEvent(&eventoBno); i++) {
    switch (eventoBno.sensorId) {
      case SH2_GAME_ROTATION_VECTOR:
        qw = eventoBno.un.gameRotationVector.real;
        qx = eventoBno.un.gameRotationVector.i;
        qy = eventoBno.un.gameRotationVector.j;
        qz = eventoBno.un.gameRotationVector.k;
        break;
      case SH2_GYROSCOPE_CALIBRATED:
        gx = eventoBno.un.gyroscope.x;
        gy = eventoBno.un.gyroscope.y;
        gz = eventoBno.un.gyroscope.z;
        break;
      case SH2_LINEAR_ACCELERATION:
        ax = eventoBno.un.linearAcceleration.x;
        ay = eventoBno.un.linearAcceleration.y;
        az = eventoBno.un.linearAcceleration.z;
        break;
      default:
        break;
    }
  }
}

void leerGPS() {
  while (gpsSerial.available()) gps.encode(gpsSerial.read());
}

void armarServos() {
  if (servosArmados) return;

  ESP32PWM::allocateTimer(0);
  ESP32PWM::allocateTimer(1);
  ESP32PWM::allocateTimer(2);
  ESP32PWM::allocateTimer(3);

  for (int i = 0; i < 4; i++) {
    servos[i].setPeriodHertz(SERVO_HZ);
    servos[i].attach(PIN_SERVO[i], SERVO_MIN_US, SERVO_MAX_US);
    servos[i].writeMicroseconds(servoCentroUs[i]);
  }
  servosArmados = true;
  Serial.println("SERVOS ARMADOS A 333 Hz Y CENTRADOS");
}

void desarmarServos() {
  for (int i = 0; i < 4; i++) {
    if (servos[i].attached()) {
      servos[i].writeMicroseconds(servoCentroUs[i]);
      delay(50);
      servos[i].detach();
    }
  }
  servosArmados = false;
  Serial.println("SERVOS DESARMADOS: sin señal PWM");
}

void moverServo(int numero, float grados) {
  if (!servosArmados) {
    Serial.println("ERROR: primero escribe ARMAR SERVOS X08");
    return;
  }
  if (numero < 1 || numero > 4 || !isfinite(grados) || fabs(grados) > 10.0f) {
    Serial.println("ERROR: usa SERVO numero grados; numero 1-4, grados -10 a +10");
    return;
  }

  int i = numero - 1;
  float pulso = servoCentroUs[i] + servoDireccion[i] * grados * US_POR_GRADO;
  pulso = constrain(pulso, (float)SERVO_MIN_US, (float)SERVO_MAX_US);
  servos[i].writeMicroseconds((int)roundf(pulso));
  Serial.printf("Servo %d: %.2f grados, %.0f us\n", numero, grados, pulso);
}

void centrarServos() {
  if (!servosArmados) {
    Serial.println("Los servos no estan armados");
    return;
  }
  for (int i = 0; i < 4; i++) servos[i].writeMicroseconds(servoCentroUs[i]);
  Serial.println("Cuatro servos centrados");
}

void probarSD() {
  if (!sdOK) {
    Serial.println("SD: ERROR, no inicializada");
    return;
  }
  digitalWrite(PIN_NRF_CSN, HIGH);
  File archivo = SD.open("/diagnostico.txt", FILE_APPEND);
  if (!archivo) {
    Serial.println("SD: ERROR al abrir /diagnostico.txt");
    return;
  }
  archivo.printf("tiempo=%lu presion=%.1f temperatura=%.2f\n",
                 (unsigned long)millis(), presionPa, temperaturaC);
  archivo.flush();
  archivo.close();
  Serial.println("SD: OK, se escribio /diagnostico.txt");
}

#pragma pack(push, 1)
struct PaqueteNavegacion {
  uint16_t magia;
  uint8_t tipo;
  uint8_t version;
  uint16_t secuencia;
  uint8_t estado;
  uint8_t banderas;
  int32_t latitudE7;
  int32_t longitudE7;
  int32_t alturaGpsCm;
  int32_t alturaBaroCm;
  uint32_t presionPa;
  int16_t temperaturaCentiC;
  int16_t velocidadCms;
};
#pragma pack(pop)
static_assert(sizeof(PaqueteNavegacion) == 32, "Paquete debe medir 32 bytes");

void probarRadio() {
  if (!radioOK) {
    Serial.println("RADIO: ERROR, no inicializado");
    return;
  }
  if (bmpOK && bmp.performReading()) {
    presionPa = bmp.pressure;
    temperaturaC = bmp.temperature;
    altitudBmpM = 44330.0f *
      (1.0f - powf(presionPa / (PRESION_NIVEL_MAR_HPA * 100.0f), 0.19029495f));
  }
  PaqueteNavegacion paquete = {};
  paquete.magia = 0xCA57;
  paquete.tipo = 2;
  paquete.version = 2;
  paquete.secuencia = (uint16_t)millis();
  paquete.estado = 2;
  paquete.banderas = (bnoOK ? 0x01 : 0) | (bmpOK ? 0x02 : 0) |
                      (sdOK ? 0x04 : 0) | (radioOK ? 0x08 : 0) |
                      (gps.location.isValid() ? 0x10 : 0);
  if (gps.location.isValid()) {
    paquete.latitudE7 = (int32_t)llround(gps.location.lat() * 10000000.0);
    paquete.longitudE7 = (int32_t)llround(gps.location.lng() * 10000000.0);
  }
  if (gps.altitude.isValid())
    paquete.alturaGpsCm = (int32_t)lround(gps.altitude.meters() * 100.0);
  if (isfinite(altitudBmpM)) paquete.alturaBaroCm = (int32_t)lroundf(altitudBmpM * 100.0f);
  if (isfinite(presionPa)) paquete.presionPa = (uint32_t)lroundf(presionPa);
  if (isfinite(temperaturaC)) paquete.temperaturaCentiC = (int16_t)lroundf(temperaturaC * 100.0f);

  digitalWrite(PIN_SD_CS, HIGH);
  bool recibido = radio.write(&paquete, sizeof(paquete));
  Serial.println(recibido ? "RADIO: OK, ACK recibido" :
                            "RADIO: sin ACK; enciende la estacion terrestre");
}

void mostrarAyuda() {
  Serial.println("\n========== COMANDOS ==========");
  Serial.println("I2C");
  Serial.println("ESTADO");
  Serial.println("DATOS ON");
  Serial.println("DATOS OFF");
  Serial.println("PROBAR SD");
  Serial.println("PROBAR RADIO");
  Serial.println("ARMAR SERVOS X08");
  Serial.println("SERVO 1 3");
  Serial.println("SERVO 1 -3");
  Serial.println("CENTRAR SERVOS");
  Serial.println("DESARMAR SERVOS");
  Serial.println("AYUDA");
  Serial.println("==============================\n");
}

void procesarComando(char *comando) {
  if (strcmp(comando, "I2C") == 0) {
    escanearI2C();
  } else if (strcmp(comando, "ESTADO") == 0) {
    Serial.printf("BNO085=%s BMP390=%s SD=%s RADIO=%s GPS_DATOS=%lu GPS_FIX=%s LAT=%.7f LON=%.7f ALT_GPS=%.2fm P=%.1fPa ALT_BMP=%.2fm PPS=%lu SERVOS=%s\n",
                  bnoOK ? "OK" : "ERROR", bmpOK ? "OK" : "ERROR",
                  sdOK ? "OK" : "ERROR", radioOK ? "OK" : "ERROR",
                  (unsigned long)gps.charsProcessed(),
                  gps.location.isValid() ? "SI" : "NO",
                  gps.location.isValid() ? gps.location.lat() : NAN,
                  gps.location.isValid() ? gps.location.lng() : NAN,
                  gps.altitude.isValid() ? gps.altitude.meters() : NAN,
                  presionPa, altitudBmpM,
                  (unsigned long)pulsosPPS, servosArmados ? "ARMADOS" : "APAGADOS");
  } else if (strcmp(comando, "DATOS ON") == 0) {
    transmitirDatos = true;
  } else if (strcmp(comando, "DATOS OFF") == 0) {
    transmitirDatos = false;
  } else if (strcmp(comando, "PROBAR SD") == 0) {
    probarSD();
  } else if (strcmp(comando, "PROBAR RADIO") == 0) {
    probarRadio();
  } else if (strcmp(comando, "ARMAR SERVOS X08") == 0) {
    armarServos();
  } else if (strcmp(comando, "CENTRAR SERVOS") == 0) {
    centrarServos();
  } else if (strcmp(comando, "DESARMAR SERVOS") == 0) {
    desarmarServos();
  } else if (strncmp(comando, "SERVO ", 6) == 0) {
    int numero;
    float grados;
    if (sscanf(comando + 6, "%d %f", &numero, &grados) == 2)
      moverServo(numero, grados);
    else
      Serial.println("Formato: SERVO numero grados");
  } else if (strcmp(comando, "AYUDA") == 0 || comando[0] == '\0') {
    mostrarAyuda();
  } else {
    Serial.println("Comando desconocido. Escribe AYUDA");
  }
}

void leerComandosSerie() {
  static char linea[64];
  static size_t longitud = 0;

  while (Serial.available()) {
    char c = (char)Serial.read();
    if (c == '\r') continue;
    if (c == '\n') {
      linea[longitud] = '\0';
      procesarComando(linea);
      longitud = 0;
    } else if (longitud < sizeof(linea) - 1) {
      linea[longitud++] = c;
    } else {
      longitud = 0;
    }
  }
}

void imprimirDatos() {
  if (!transmitirDatos || millis() - ultimaImpresionMs < 100) return;
  ultimaImpresionMs = millis();

  if (bmpOK && bmp.performReading()) {
    presionPa = bmp.pressure;
    temperaturaC = bmp.temperature;
    altitudBmpM = 44330.0f *
      (1.0f - powf(presionPa / (PRESION_NIVEL_MAR_HPA * 100.0f), 0.19029495f));
  }

  Serial.printf("DATOS t=%lu | Q=%.5f %.5f %.5f %.5f | G=%.3f %.3f %.3f rad/s | A=%.2f %.2f %.2f m/s2 | BMP: P=%.1f Pa ALT=%.2f m T=%.2f C | GPS=%s LAT=%.7f LON=%.7f ALT=%.2f m VEL=%.2f km/h SAT=%lu PPS=%lu\n",
                (unsigned long)millis(), qw, qx, qy, qz, gx, gy, gz,
                ax, ay, az, presionPa, altitudBmpM, temperaturaC,
                gps.location.isValid() ? "FIX" : "SIN_FIX",
                gps.location.isValid() ? gps.location.lat() : NAN,
                gps.location.isValid() ? gps.location.lng() : NAN,
                gps.altitude.isValid() ? gps.altitude.meters() : NAN,
                gps.speed.isValid() ? gps.speed.kmph() : NAN,
                gps.satellites.isValid() ? (unsigned long)gps.satellites.value() : 0UL,
                (unsigned long)pulsosPPS);
}

void setup() {
  Serial.begin(115200);
  delay(1000);
  Serial.println("\nSULTANA DEL NORTE - DIAGNOSTICO ESP32-S3");
  Serial.println("PRIMERA PRUEBA DE SERVOS SIN VARILLAJES NI CANARDS");

  Wire.begin(PIN_I2C_SDA, PIN_I2C_SCL, 400000);
  escanearI2C();

  bnoOK = bno.begin_I2C(0x4A, &Wire) && activarReportesBNO();
  bmpOK = bmp.begin_I2C(0x77, &Wire);
  if (!bmpOK) bmpOK = bmp.begin_I2C(0x76, &Wire);
  if (bmpOK) {
    bmp.setTemperatureOversampling(BMP3_OVERSAMPLING_2X);
    bmp.setPressureOversampling(BMP3_OVERSAMPLING_8X);
    bmp.setIIRFilterCoeff(BMP3_IIR_FILTER_COEFF_3);
    bmp.setOutputDataRate(BMP3_ODR_50_HZ);
  }

  gpsSerial.setRxBufferSize(2048);
  gpsSerial.begin(9600, SERIAL_8N1, PIN_GPS_RX, PIN_GPS_TX);
  pinMode(PIN_GPS_PPS, INPUT);
  attachInterrupt(digitalPinToInterrupt(PIN_GPS_PPS), interrupcionPPS, RISING);

  pinMode(PIN_SD_CS, OUTPUT);
  pinMode(PIN_NRF_CSN, OUTPUT);
  digitalWrite(PIN_SD_CS, HIGH);
  digitalWrite(PIN_NRF_CSN, HIGH);
  SPI.begin(PIN_SPI_SCK, PIN_SPI_MISO, PIN_SPI_MOSI);

  sdOK = SD.begin(PIN_SD_CS, SPI, 16000000);
  radioOK = radio.begin(&SPI);
  if (radioOK) {
    radio.setChannel(RADIO_CANAL);
    radio.setDataRate(RF24_250KBPS);
    radio.setPALevel(RF24_PA_LOW);  // Baja potencia para prueba de mesa
    radio.setCRCLength(RF24_CRC_16);
    radio.setRetries(3, 5);
    radio.setPayloadSize(sizeof(PaqueteNavegacion));
    radio.openWritingPipe(RADIO_DIRECCION);
    radio.stopListening();
  }

  Serial.printf("INICIO: BNO085=%s BMP390=%s SD=%s RADIO=%s\n",
                bnoOK ? "OK" : "ERROR", bmpOK ? "OK" : "ERROR",
                sdOK ? "OK" : "ERROR", radioOK ? "OK" : "ERROR");
  mostrarAyuda();
}

void loop() {
  leerComandosSerie();
  leerGPS();
  leerBNO();
  imprimirDatos();
  delay(1);
}

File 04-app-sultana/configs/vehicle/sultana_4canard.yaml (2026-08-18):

schema_version: 1
vehicle_id: sultana-four-canard-preliminary
parameter_registry_yaml: data/calibration/parameter_registry.yaml
geometry:
  diameter_m: 0.0508
  reference_area_m2: 0.0020268
  body_length_m: 0.902
  cp_m: 0.78
mass:
  dry_mass_kg: 1.20
  propellant_mass_kg: 0.25
  cg_dry_m: 0.63
  cg_wet_m: 0.72
  inertia_dry_kg_m2: [0.025, 0.22, 0.22]
  inertia_wet_kg_m2: [0.028, 0.25, 0.25]
  mass_curve_csv: data/mass_profiles/preliminary_mass_properties.csv
aerodynamics:
  cd_base: 0.55
  aero_table_csv: data/aerodynamics/preliminary_aero_table.csv
  body_cn_alpha_per_rad: 2.0
  cd_alpha2: 0.08
  cd_reynolds_per_log: 0.0
  reference_reynolds: 100000.0
  angular_damping_nm_per_rad_s: 0.04
  canard_area_m2: 0.0012
  canard_arm_m: 0.42
  canard_cl_alpha_per_rad: 2.5
actuators:
  count: 4
  max_canard_deflection_deg: 15
  # KST X08H Plus at its nominal 7.4 V: 0.12 s / 60 degrees.
  max_canard_rate_deg_s: 500
  canard_command_delay_s: 0.02
  canard_mount_offset_rad: [0.0, 0.0, 0.0, 0.0]
recovery:
  # Paracaídas circular medido: Ø 0.50 m; A = π(0.25 m)².
  parachute_area_m2: 0.19634954
  parachute_cd: 1.50
  parachute_deploy_delay_s: 0.25
  parachute_inflation_time_s: 0.80
propulsion:
  selected_motor_id: knsb_20cm
  # La curva de empuje sigue siendo estimada hasta contar con ensayo estático.
  # RocketCEA calcula el rendimiento termoquímico de equilibrio, no la tasa de
  # regresión del grano ni la resistencia del contenedor de PVC.
  rocketcea:
    chamber_pressure_pa: 3447378.65 # 500 psia, supuesto preliminar
    expansion_ratio: 5.0            # Ae/At, supuesto preliminar
    catalyst_mass_g: 1.0            # óxido de hierro declarado por el usuario
    status: "preliminar: faltan puerto/grano, garganta, tobera y ensayo estático"
  motors:
    - id: knsb_10cm
      label: "KNSB 10 cm · estimado"
      grain_length_m: 0.10
      propellant_mass_kg: 0.125
      burn_time_s: 1.0
      thrust_curve_csv: data/thrust_curves/knsb_10cm_estimated.csv
    - id: knsb_15cm
      label: "KNSB 15 cm · estimado"
      grain_length_m: 0.15
      propellant_mass_kg: 0.188
      burn_time_s: 1.5
      thrust_curve_csv: data/thrust_curves/knsb_15cm_estimated.csv
    - id: knsb_20cm
      label: "KNSB 20 cm · estimado"
      grain_length_m: 0.20
      propellant_mass_kg: 0.250
      burn_time_s: 2.0
      thrust_curve_csv: data/thrust_curves/preliminary_knsb.csv
  burn_time_s: 2.0
  thrust_curve_csv: data/thrust_curves/preliminary_knsb.csv
  propellant:
    oxidizer: potassium_nitrate
    fuel: sorbitol
    mixture_notes: "Declarado por el usuario: 70% sorbitol, 30% nitrato de potasio y 1 g de óxido de hierro. La composición termoquímica exacta y la geometría aún están pendientes."
    rocketcea_status: preliminary_equilibrium_report; grain_and_nozzle_geometry_pending
physical_inventory:
  body:
    material: "PVC cédula 40 nominal 2 in"
    nominal_schedule40_od_m: 0.060325
    nominal_schedule40_wall_m: 0.003912
    cad_main_body_od_m_approx: 0.0798
    status: "INCONSISTENCIA: CAD y especificación nominal no coinciden; medir OD real con calibrador antes de calibrar aerodinámica/masa."
  aerodynamic_surfaces: {material: "PLA, relleno 50%", status: "Masa y densidad efectiva pendientes"}
  motor_case: {material: "PVC sanitario nominal 1½ in", status: "Tobera y dimensiones internas pendientes"}
  electronics: {mass_kg: 0.250, status: "Posición longitudinal pendiente"}
  servos:
    model: "KST X08/X08H Plus"
    count: 4
    actuator_mass_kg: 0.036
    installed_system_mass_kg: 0.150
    status: "150 g declarado por el usuario para servos instalados; 36 g corresponde sólo a cuatro actuadores y el resto cubre soportes/cableado. Confirmar inclusión en dry_mass_kg."
  parachute: {mass_kg: 0.400, diameter_m: 0.50, lines: 10, status: "Confirmar si ya está incluida en dry_mass_kg"}
calibration:
  thrust_curve: false
  mass_properties: false
  aerodynamics: false

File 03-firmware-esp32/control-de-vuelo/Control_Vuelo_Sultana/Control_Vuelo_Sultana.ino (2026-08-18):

/*
  CONTROL DE VUELO SULTANA DEL NORTE - ESP32-S3 - ARCHIVO UNICO PARA ARDUINO IDE

  Placa: ESP32S3 Dev Module
  Monitor serie: 115200 baud

  CONTROL:
  - Actitud mediante cuaterniones (sin singularidades de Euler).
  - Lazo externo de actitud + PID interno de velocidad angular.
  - Anti-windup, derivada filtrada, saturacion y limite de velocidad de servos.
  - Kalman vertical de 3 estados: altura, velocidad y sesgo del acelerometro.
  - Mezcla 4x3 para roll, pitch y yaw.
  - microSD a 50 Hz y nRF24 a 20 Hz en el segundo nucleo.

  SEGURIDAD:
  Los dos bloqueos siguientes vienen en false. NO ponerlos en true hasta
  calibrar centros, sentidos y matriz de mezcla con el sketch Diagnostico.
*/

#include <Wire.h>
#include <SPI.h>
#include <SD.h>
#include <Adafruit_BNO08x.h>
#include <Adafruit_BMP3XX.h>
#include <ESP32Servo.h>
#include <RF24.h>
#include <TinyGPS++.h>

// Declaraciones adelantadas requeridas por el preprocesador de archivos .ino.
struct PaqueteControl;
struct PaqueteNavegacion;
struct DatosCompartidos;

// ========================= BLOQUEOS DE SEGURIDAD =========================
const bool PERMITIR_MOVIMIENTO_CANARDS = false;
const bool MEZCLA_Y_SENTIDOS_VALIDADOS = false;
const bool ARMADO_AUTOMATICO = false;
const bool HABILITAR_SALIDA_PARACAIDAS = false;

// ============================== PINES ====================================
const int PIN_BNO_RST = 4;
const int PIN_BNO_INT = 5;
const int PIN_SD_CS = 6;
const int PIN_NRF_IRQ = 7;
const int PIN_I2C_SCL = 9;
const int PIN_NRF_CSN = 10;
const int PIN_SPI_MOSI = 11;
const int PIN_SPI_MISO = 12;
const int PIN_SPI_SCK = 13;
const int PIN_NRF_CE = 14;
const int PIN_GPS_PPS = 15;
const int PIN_GPS_RX = 16;
const int PIN_GPS_TX = 17;
const int PIN_I2C_SDA = 18;
const int PIN_SERVO[4] = {41, 2, 21, 47};
// GPIO libre propuesto. Debe conectarse SOLO a la entrada logica de un
// controlador externo de despliegue; nunca directamente a una carga.
const int PIN_ALERTA_PARACAIDAS = 40;

// =========================== KST X08 PLUS ================================
const int SERVO_HZ = 333;
const int SERVO_MIN_US = 900;
const int SERVO_MAX_US = 2100;
int servoCentroUs[4] = {1500, 1500, 1500, 1500};
int servoDireccion[4] = {+1, +1, +1, +1};  // CALIBRAR UNO POR UNO
const float US_POR_GRADO = 1000.0f / 120.0f;
const float ANGULO_MAX_CANARD = 12.0f;
const float VELOCIDAD_MAX_CANARD_GRADOS_S = 400.0f;

// Filas: servo 1..4. Columnas: roll, pitch, yaw.
// ES UNA HIPOTESIS INICIAL. Debe validarse con la geometria fisica real.
float mezclaCanards[4][3] = {
  {+1.0f, +1.0f,  0.0f},
  {+1.0f, -1.0f,  0.0f},
  {-1.0f,  0.0f, +1.0f},
  {-1.0f,  0.0f, -1.0f}
};

// =========================== CONFIGURACION ===============================
const uint32_t PERIODO_CONTROL_US = 5000;       // 200 Hz
const uint32_t PERIODO_BNO_US = 5000;           // 200 Hz
const uint32_t PERIODO_BAROMETRO_US = 20000;    // 50 Hz
const uint32_t PERIODO_LOG_MS = 20;              // 50 Hz
const uint32_t PERIODO_RADIO_MS = 50;            // 20 Hz
const uint32_t TIEMPO_CALIBRACION_MS = 5000;

// Ganancias iniciales de banco: roll, pitch, yaw. NO son ganancias finales.
float KpActitud[3] = {2.2f, 3.0f, 3.0f};
float KpRate[3] = {1.2f, 2.0f, 2.0f};
float KiRate[3] = {0.15f, 0.25f, 0.25f};
float KdRate[3] = {0.025f, 0.035f, 0.035f};
const float CORTE_DERIVADA_HZ = 25.0f;
const float GANANCIA_ANTI_WINDUP = 6.0f;
const float RATE_MAX_RAD_S = 5.0f;

const float Q_DINAMICA_REFERENCIA_PA = 600.0f;
const float ESCALA_Q_MIN = 0.30f;

const float RUIDO_ACEL_M_S2 = 1.8f;
const float CAMINATA_SESGO_M_S2 = 0.08f;
const float RUIDO_BARO_M = 1.5f;
const float INNOVACION_BARO_MAX_M = 30.0f;

const float ACEL_LANZAMIENTO_M_S2 = 12.0f;
const uint32_t CONFIRMAR_LANZAMIENTO_MS = 100;
const float ACEL_BURNOUT_M_S2 = 3.0f;
const uint32_t CONFIRMAR_BURNOUT_MS = 300;
const float VELOCIDAD_APOGEO_M_S = -1.5f;
const float ALTURA_MIN_APOGEO_M = 15.0f;
const uint32_t VUELO_ACTIVO_MAX_MS = 45000;
const float VELOCIDAD_ALERTA_CAIDA_M_S = -1.5f;
const float ALTURA_MIN_ALERTA_PARACAIDAS_M = 15.0f;
const uint32_t CONFIRMAR_CAIDA_MS = 250;
const uint32_t PULSO_ALERTA_PARACAIDAS_MS = 500;

const uint32_t TIMEOUT_ACTITUD_US = 100000;
const uint32_t TIMEOUT_GYRO_US = 100000;
const uint32_t TIMEOUT_BARO_US = 250000;

const byte DIRECCION_RADIO[6] = "SNL01";
const byte CANAL_RADIO = 76;  // 2476 MHz

// ========================== MATEMATICA 3D ================================
struct Vector3 {
  float x, y, z;
  Vector3(float X = 0, float Y = 0, float Z = 0) : x(X), y(Y), z(Z) {}
  float norma() const { return sqrtf(x*x + y*y + z*z); }
};

struct Cuaternion {
  float w, x, y, z;
  Cuaternion(float W = 1, float X = 0, float Y = 0, float Z = 0)
      : w(W), x(X), y(Y), z(Z) {}

  bool normalizar() {
    float n2 = w*w + x*x + y*y + z*z;
    if (!isfinite(n2) || n2 < 0.25f || n2 > 2.25f) return false;
    float inv = 1.0f / sqrtf(n2);
    w *= inv; x *= inv; y *= inv; z *= inv;
    return true;
  }

  Cuaternion conjugado() const { return Cuaternion(w, -x, -y, -z); }

  Cuaternion operator*(const Cuaternion &b) const {
    return Cuaternion(
      w*b.w - x*b.x - y*b.y - z*b.z,
      w*b.x + x*b.w + y*b.z - z*b.y,
      w*b.y - x*b.z + y*b.w + z*b.x,
      w*b.z + x*b.y - y*b.x + z*b.w
    );
  }

  Vector3 rotar(const Vector3 &v) const {
    Cuaternion resultado = (*this) * Cuaternion(0, v.x, v.y, v.z) * conjugado();
    return Vector3(resultado.x, resultado.y, resultado.z);
  }
};

float limitar(float valor, float minimo, float maximo) {
  return valor < minimo ? minimo : (valor > maximo ? maximo : valor);
}

Vector3 errorRotacionMinima(const Cuaternion &actual, const Cuaternion &objetivo) {
  Cuaternion error = actual.conjugado() * objetivo;
  error.normalizar();
  if (error.w < 0) {
    error.w = -error.w; error.x = -error.x;
    error.y = -error.y; error.z = -error.z;
  }
  float normaVector = sqrtf(error.x*error.x + error.y*error.y + error.z*error.z);
  if (normaVector < 1.0e-6f)
    return Vector3(2*error.x, 2*error.y, 2*error.z);
  float angulo = 2.0f * atan2f(normaVector, error.w);
  float escala = angulo / normaVector;
  return Vector3(error.x*escala, error.y*escala, error.z*escala);
}
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

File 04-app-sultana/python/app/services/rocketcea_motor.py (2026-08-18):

"""Traceable preliminary RocketCEA reporting for the declared KNSB motor.

This module is deliberately limited to equilibrium chamber/nozzle performance.
It does not create a flight thrust curve: grain port, throat diameter, nozzle
geometry and a static firing are still required for that calibration.
"""
from __future__ import annotations

from dataclasses import dataclass
from typing import Any

PSI_TO_PA = 6_894.757293168
STANDARD_AMBIENT_PRESSURE_PSI = 14.6959


@dataclass(frozen=True)
class RocketCeaReport:
    motor_id: str
    chamber_pressure_pa: float
    expansion_ratio: float
    sorbitol_mass_fraction: float
    kno3_mass_fraction: float
    fe2o3_mass_fraction: float
    ideal_isp_s: float
    cstar_m_s: float
    chamber_temperature_k: float
    sea_level_cf: float
    status: str


def _catalogue_motor(scenario: object, motor_id: str | None = None) -> dict[str, Any]:
    propulsion = scenario.vehicle["propulsion"]
    wanted = motor_id or str(propulsion.get("selected_motor_id", ""))
    for motor in propulsion.get("motors", []):
        if str(motor.get("id", "")) == wanted:
            return motor
    raise ValueError(f"Motor RocketCEA no configurado: {wanted}")


def _card(propellant_mass_kg: float, catalyst_mass_g: float) -> tuple[str, tuple[float, float, float]]:
    """Build the CEA reactant card from the user's mass composition.

    Sorbitol's condensed-phase heat of formation is -1353.7 kJ/mol (NIST
    SRD 69), or -323.26 cal/mol.  KNO3(a) is a NASA CEA thermo species.
    Fe2O3 is represented as the declared catalyst/inert constituent.
    """
    total_g = max(float(propellant_mass_kg) * 1_000.0, 1e-9)
    fe2o3_g = min(max(float(catalyst_mass_g), 0.0), total_g * 0.99)
    mixture_g = total_g - fe2o3_g
    sorbitol = 0.70 * mixture_g / total_g
    kno3 = 0.30 * mixture_g / total_g
    fe2o3 = fe2o3_g / total_g
    card = f"""
name C6H14O6(S) C 6 H 14 O 6 wt%={100.0 * sorbitol:.9g}
h,cal=-323.26 t(k)=298.15 rho=1.489
name KNO3(a) K 1 N 1 O 3 wt%={100.0 * kno3:.9g}
h,cal=-118069 t(k)=298.15 rho=2.109
name Fe2O3(S) Fe 2 O 3 wt%={100.0 * fe2o3:.9g}
h,cal=-197000 t(k)=298.15 rho=5.24
"""
    return card, (sorbitol, kno3, fe2o3)


def rocketcea_motor_report(scenario: object, motor_id: str | None = None) -> RocketCeaReport:
    """Evaluate one catalogue motor using the declared preliminary CEA inputs."""
    motor = _catalogue_motor(scenario, motor_id)
    model = scenario.vehicle["propulsion"].get("rocketcea", {})
    chamber_pressure_pa = float(model.get("chamber_pressure_pa", 500.0 * PSI_TO_PA))
    expansion_ratio = float(model.get("expansion_ratio", 5.0))
    catalyst_mass_g = float(model.get("catalyst_mass_g", 1.0))
    card, fractions = _card(float(motor["propellant_mass_kg"]), catalyst_mass_g)
    try:
        from rocketcea.cea_obj import CEA_Obj, add_new_propellant
    except (ImportError, OSError) as exc:  # Frozen installs may omit propulsion data files.
        raise RuntimeError("RocketCEA no está instalado; instala el extra de propulsión.") from exc

    # A unique card name prevents a selector change from reusing another
    # motor's catalyst fraction in RocketCEA's process-global card registry.
    name = f"SULTANA_{motor['id']}_{int(round(catalyst_mass_g * 1_000))}mg"
    add_new_propellant(name, card)
    cea = CEA_Obj(propName=name)
    chamber_pressure_psi = chamber_pressure_pa / PSI_TO_PA
    ideal_isp = float(cea.get_Isp(Pc=chamber_pressure_psi, eps=expansion_ratio))
    cstar_m_s = float(cea.get_Cstar(Pc=chamber_pressure_psi)) * 0.3048
    temperature_k = float(cea.get_Tcomb(Pc=chamber_pressure_psi))
    _, sea_level_cf, _ = cea.get_PambCf(Pc=chamber_pressure_psi, eps=expansion_ratio, Pamb=STANDARD_AMBIENT_PRESSURE_PSI)
    return RocketCeaReport(
        motor_id=str(motor["id"]), chamber_pressure_pa=chamber_pressure_pa, expansion_ratio=expansion_ratio,
        sorbitol_mass_fraction=fractions[0], kno3_mass_fraction=fractions[1], fe2o3_mass_fraction=fractions[2],
        ideal_isp_s=ideal_isp, cstar_m_s=cstar_m_s, chamber_temperature_k=temperature_k,
        sea_level_cf=float(sea_level_cf),
        status="CEA de equilibrio preliminar; no sustituye curva de empuje medida ni diseño estructural.",
    )

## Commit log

2026-08-18 feat: publish cleaned ESP32 firmware
2026-08-18 feat: import Sultana desktop application sources
    [aero_table.csv, ensamble_naca_661_212.stl, ensamble_todo_v2.stl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]
2026-08-18 docs: curate CAD CFD and electronics assets
    [INVENTARIO.csv, sultana-del-norte-final-naca.stl]
2026-08-18 docs: curate technical reports and attributions
    [INVENTARIO.csv]
2026-08-18 docs: finalize v1.0.0 release materials
